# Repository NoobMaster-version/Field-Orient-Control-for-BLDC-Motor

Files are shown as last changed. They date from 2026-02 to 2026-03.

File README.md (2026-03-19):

# Field-Orient-Control-for-BLDC-Motor

STM32G431 + DRV8311H BLDC control project using STM32CubeIDE.

## Main components
- `STM32G431CBT6` (MCU)
- `DRV8311H` (3-phase gate driver)
- `AS5600` (magnetic encoder)
- `LDL1117` (voltage regulator)

This repo includes:
- `firmware/3xPWM_FOC` (FOC firmware project)
- `firmware/Open_Loop_Test_DRV8311` (open-loop bring-up test)

## Hardware

### Soldered PCB
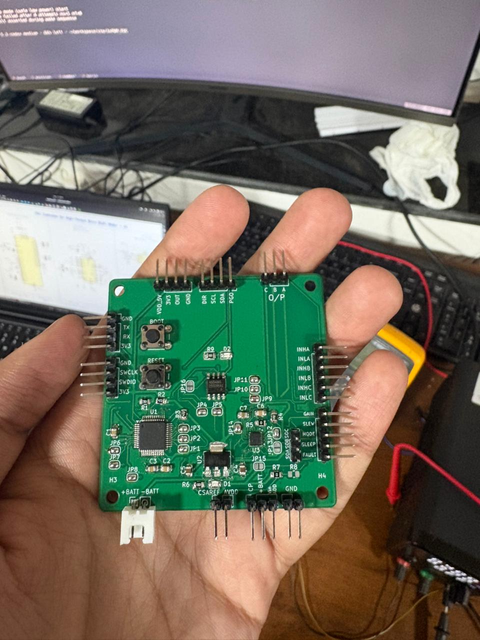
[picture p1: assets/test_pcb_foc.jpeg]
Soldered PCB


### Motor running (open-loop)
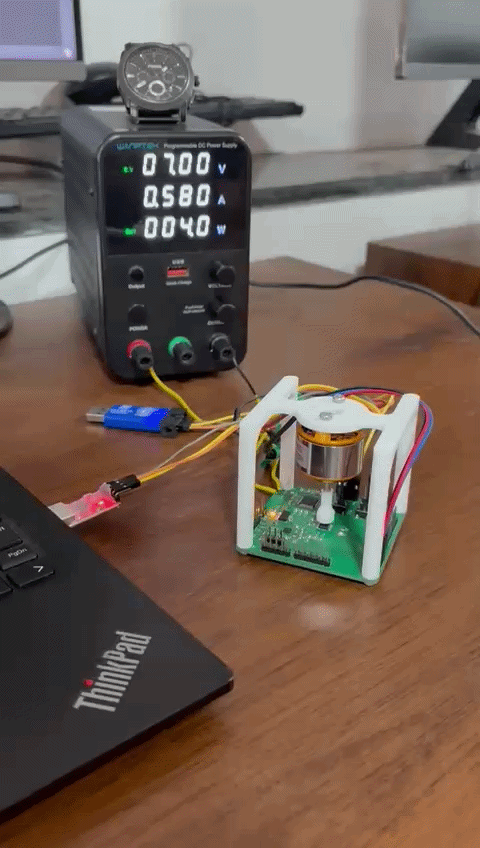
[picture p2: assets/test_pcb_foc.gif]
Open loop motor test


## PWM mode (3x PWM)

The firmware uses **3x PWM** with `TIM1` and complementary outputs to drive DRV8311:
- `INHA` from `PA8  (TIM1_CH1)`
- `INHB` from `PA9  (TIM1_CH2)`
- `INHC` from `PA10 (TIM1_CH3)`

- `INLA` from `PB13 (TIM1_CH1N)`
- `INLB` from `PB14 (TIM1_CH2N)`
- `INLC` from `PB15 (TIM1_CH3N)`

## Pin connections (STM32 -> DRV8311 / interface)

### Gate driver control
- `PA8  (TIM1_CH1)`  -> `INHA`
- `PA9  (TIM1_CH2)`  -> `INHB`
- `PA10 (TIM1_CH3)`  -> `INHC`

- `PB13 (TIM1_CH1N)` -> `INLA`
- `PB14 (TIM1_CH2N)` -> `INLB`
- `PB15 (TIM1_CH3N)` -> `INLC`

- `PC13 (GPIO)`      -> `nSLEEP`
- `PC14 (GPIO input)`-> `nFAULT` (pull-up)

### Current sensing
- `PA0 (ADC1_IN1)` -> `SOA`
- `PA1 (ADC2_IN2)` -> `SOB`
- `PA2 (ADC1_IN3)` -> `SOC`

### Encoder and debug
- `PA15 (I2C1_SCL)` -> AS5600 `SCL`
- `PB7  (I2C1_SDA)` -> AS5600 `SDA`
- `PB10 (USART3_TX)` -> UART TX (debug)
- `PB11 (USART3_RX)` -> UART RX (debug)

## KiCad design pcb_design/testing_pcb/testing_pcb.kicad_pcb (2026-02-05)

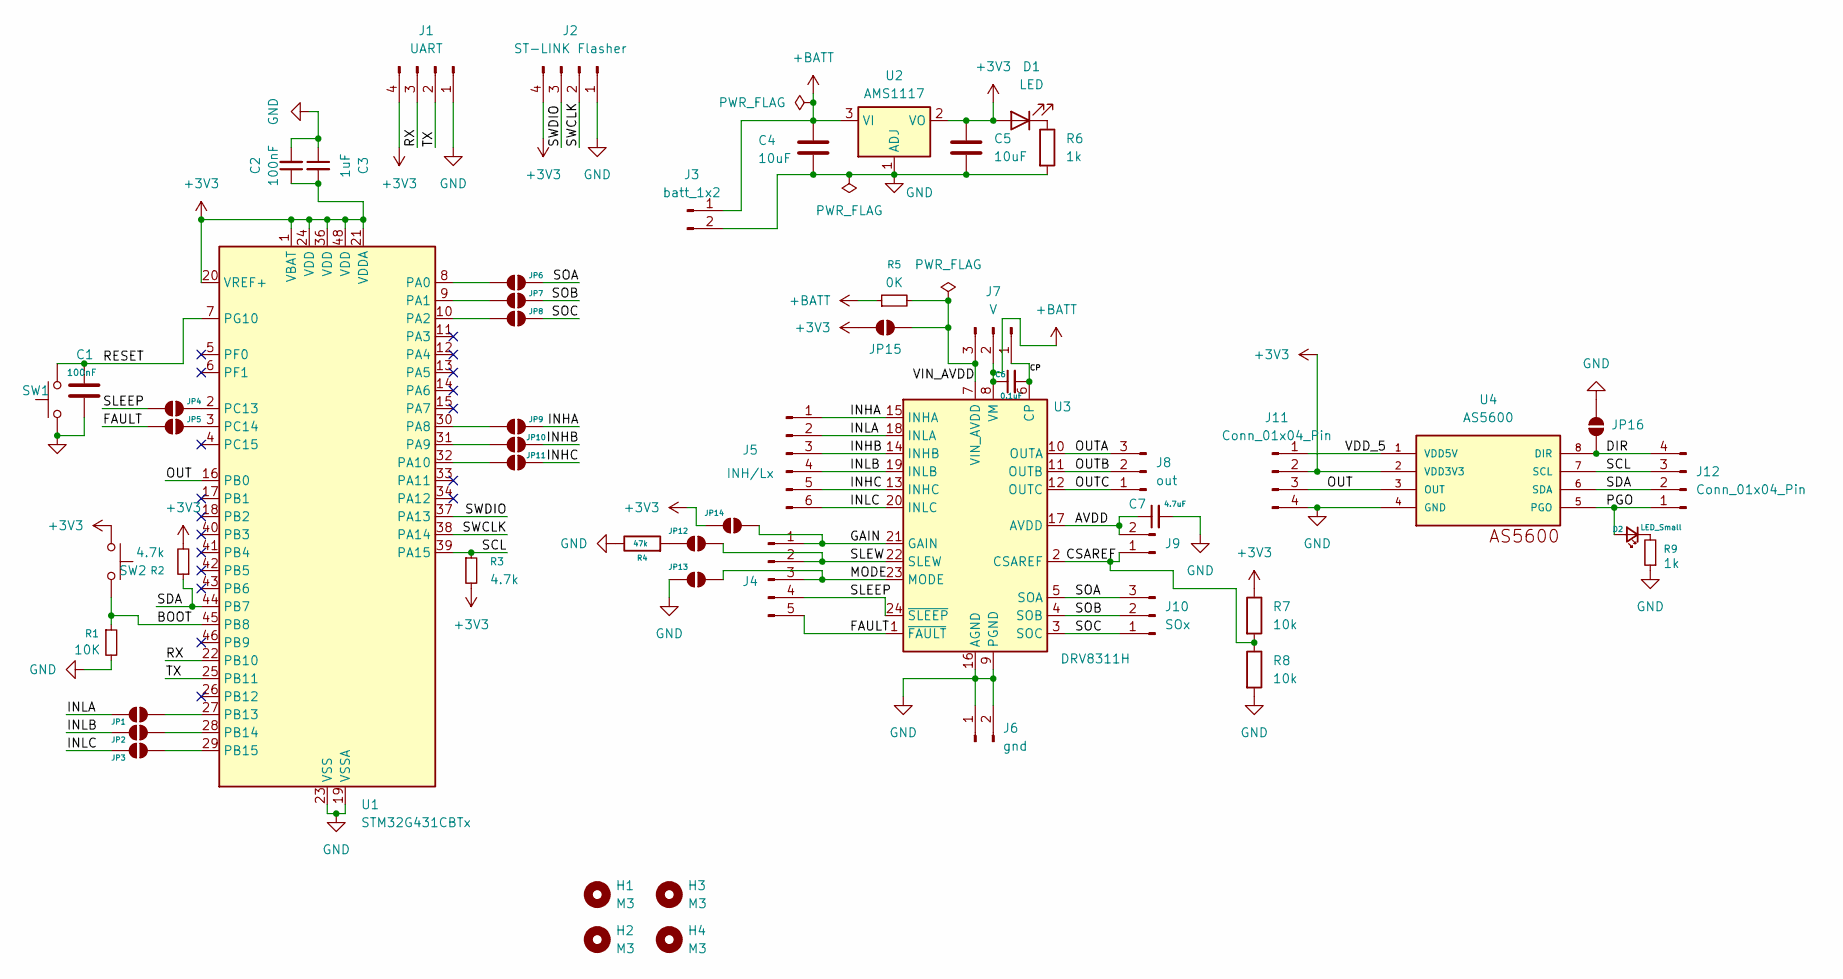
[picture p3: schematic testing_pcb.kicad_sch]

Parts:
C1: 100nF; C_0805_2012Metric_Pad1.18x1.45mm_HandSolder
C2: 100nF; C_0805_2012Metric
C3: 1uF; C_0805_2012Metric
C4, C5: 10uF; C_0805_2012Metric
C6: 0.1uF; C_0805_2012Metric
C7: 4.7uF; C_0805_2012Metric
D1: LED; LED_0805_2012Metric
D2: LED_Small; LED_0805_2012Metric
H1, H2, H3, H4: M3; MountingHole_3mm
J1: UART; PinSocket_1x04_P2.54mm_Vertical
J2: ST-LINK Flasher; PinSocket_1x04_P2.54mm_Vertical
J3: batt_1x2; PinSocket_1x02_P2.54mm_Vertical
J4: PinSocket_1x05_P2.54mm_Vertical
J5: INH/Lx; PinSocket_1x06_P2.54mm_Vertical
J6: gnd; PinSocket_1x02_P2.54mm_Vertical
J7: V; PinSocket_1x03_P2.54mm_Vertical
J8: out; PinSocket_1x03_P2.54mm_Vertical
J9: PinSocket_1x02_P2.54mm_Vertical
J10: SOx; PinSocket_1x03_P2.54mm_Vertical
J11, J12: Conn_01x04_Pin; PinSocket_1x04_P2.54mm_Vertical
JP1, JP2, JP3, JP4, JP5, JP6, JP7, JP8, JP9, JP10, JP11, JP12, JP13, JP14, JP15, JP16: SolderJumper_2_Open; SolderJumper-2_P1.3mm_Open_RoundedPad1.0x1.5mm
R1: 10K; R_0805_2012Metric
R2, R3: 4.7k; R_0805_2012Metric
R4: 47k; R_0805_2012Metric
R5: 0K; R_0805_2012Metric
R6: 1k; R_0805_2012Metric
R7, R8: 10k; R_0805_2012Metric
R9: 1k; LED_0805_2012Metric
SW1, SW2: SW_Push; SW_PUSH_6mm_H5mm
U1: STM32G431CBTx; LQFP-48_7x7mm_P0.5mm
U2: AMS1117; SOT-223-3_TabPin2
U3: DRV8311H; Texas_RRW0024A_WQFN-24-1EP_3x3mm_P0.4mm_EP1.9x1.9mm
U4: AS5600; SOIC8

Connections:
+3V3: C2.1, C3.2, C5.1, D1.2 (A), J1.4, J2.4, J11.2, JP14.1 (A), JP15.1 (A), R2.2, R3.2, R7.1, SW2.1, U1.1 (VBAT), U1.20 (VREF+), U1.21 (VDDA), U1.24 (VDD), U1.36 (VDD), U1.48 (VDD), U2.2 (VO), U4.2 (VDD3V3); also elsewhere on the board
+BATT: C4.1, C6.1, J3.1, J7.2, R5.1, U2.3 (VI), U3.8 (VM)
/AVDD: C7.1, J9.2, U3.17 (AVDD)
/BOOT: R1.1, SW2.2, U1.45 (PB8); also elsewhere on the board
/CP: C6.2, J7.1, U3.6 (CP)
/CSAREF: J9.1, R7.2, R8.1, U3.2 (CSAREF)
/DIR: J12.4, JP16.1 (A), U4.8 (DIR)
/FAULT: J4.5, JP5.1 (A), U3.1 (~FAULT)
/GAIN: J4.1, JP14.2 (B), U3.21 (GAIN)
/INHA: J5.1, JP9.2 (B), U3.15 (INHA)
/INHB: J5.3, JP10.2 (B), U3.14 (INHB)
/INHC: J5.5, JP11.2 (B), U3.13 (INHC)
/INLA: J5.2, JP1.2 (B), U3.18 (INLA)
/INLB: J5.4, JP2.2 (B), U3.19 (INLB)
/INLC: J5.6, JP3.2 (B), U3.20 (INLC)
/MODE: J4.3, JP13.2 (B), U3.23 (MODE)
/OUT: J11.3, U1.16 (PB0), U4.3 (OUT)
/OUTA: J8.3, U3.10 (OUTA)
/OUTB: J8.2, U3.11 (OUTB)
/OUTC: J8.1, U3.12 (OUTC)
/PGO: D2.2 (A), J12.1, U4.5 (PGO)
/RESET: C1.1, SW1.2, U1.7 (PG10); also elsewhere on the board
/RX: J1.3, U1.22 (PB10); also elsewhere on the board
/SCL: J12.3, R3.1, U1.39 (PA15), U4.7 (SCL)
/SDA: J12.2, R2.1, U1.44 (PB7), U4.6 (SDA)
/SLEEP: J4.4, JP4.1 (A), U3.24 (~SLEEP)
/SLEW: J4.2, JP12.2 (B), U3.22 (SLEW)
/SOA: J10.3, JP6.2 (B), U3.5 (SOA)
/SOB: J10.2, JP7.2 (B), U3.4 (SOB)
/SOC: J10.1, JP8.2 (B), U3.3 (SOC)
/SWCLK: J2.2, U1.38 (PA14)
/SWDIO: J2.3, U1.37 (PA13)
/TX: J1.2, U1.25 (PB11); also elsewhere on the board
/VDD_5: J11.1, U4.1 (VDD5V)
/VIN_AVDD: J7.3, JP15.2 (B), R5.2, U3.7 (VIN_AVDD)
GND: C1.2, C2.2, C3.1, C4.2, C5.2, C7.2, J1.1, J2.1, J3.2, J6.1, J6.2, J11.4, JP13.1 (A), JP16.2 (B), R1.2, R4.1, R6.2, R8.2, R9.1, SW1.1, U1.19 (VSSA), U1.23 (VSS), U1.35 (VSS), U1.47 (VSS), U2.1 (ADJ), U3.9 (PGND), U3.16 (AGND), U3.25 (PGND), U4.4 (GND); also elsewhere on the board
unnamed: D1.1 (K), R6.1
unnamed: D2.1 (K), R9.2
unnamed: JP1.1 (A), U1.27 (PB13)
unnamed: JP2.1 (A), U1.28 (PB14)
unnamed: JP3.1 (A), U1.29 (PB15)
unnamed: JP4.2 (B), U1.2 (PC13)
unnamed: JP5.2 (B), U1.3 (PC14)
unnamed: JP6.1 (A), U1.8 (PA0)
unnamed: JP7.1 (A), U1.9 (PA1)
unnamed: JP8.1 (A), U1.10 (PA2)
unnamed: JP9.1 (A), U1.30 (PA8)
unnamed: JP10.1 (A), U1.31 (PA9)
unnamed: JP11.1 (A), U1.32 (PA10)
unnamed: JP12.1 (A), R4.2

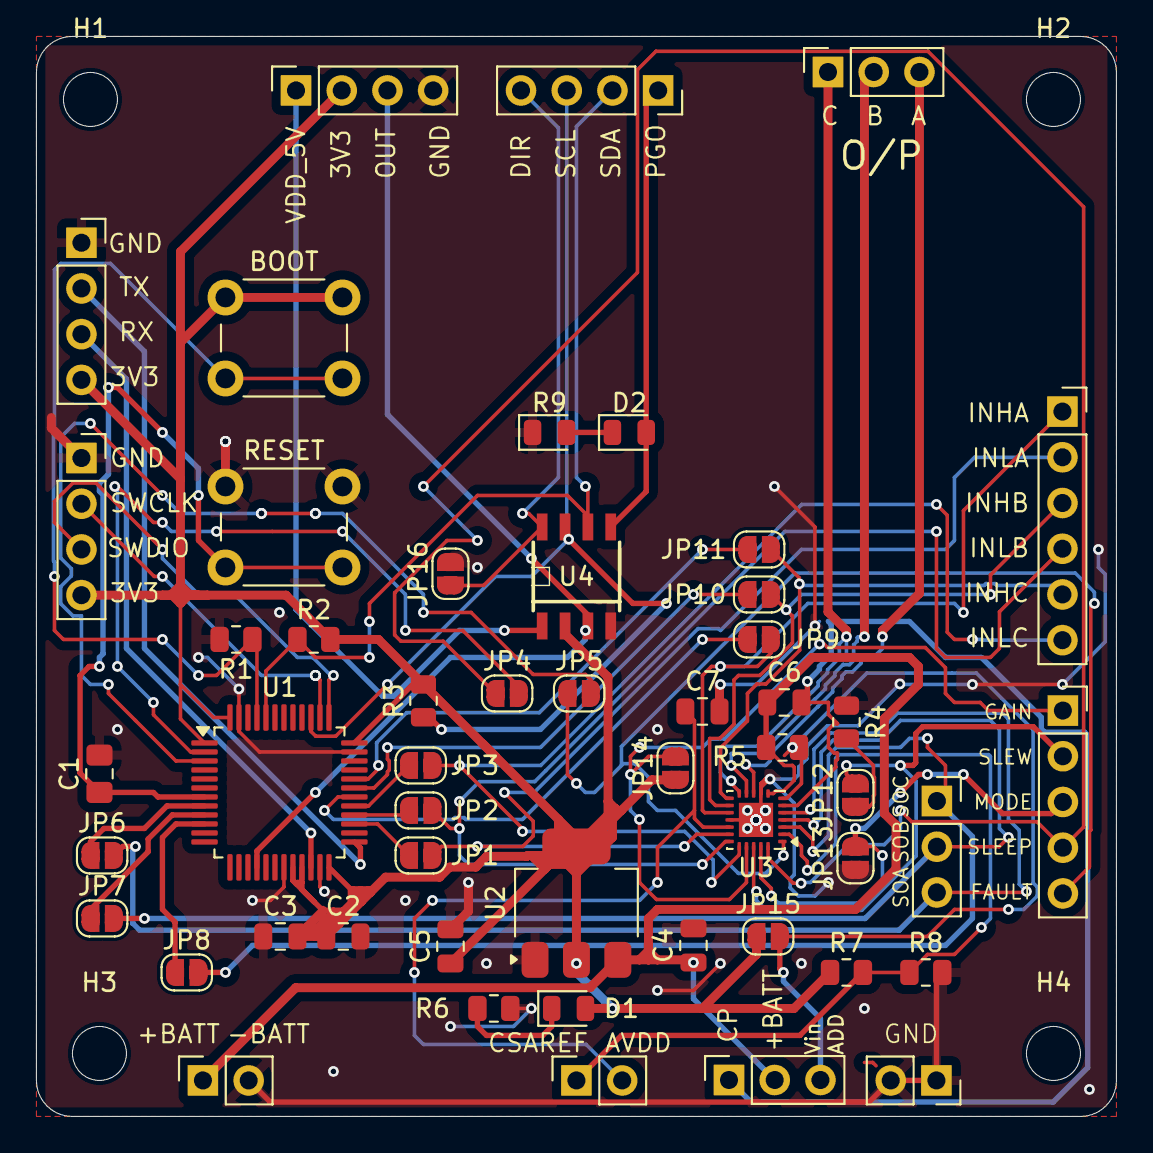
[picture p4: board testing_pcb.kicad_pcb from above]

Board: 2 copper layers, 60.0 x 60.0 mm, 56 parts (0 on the bottom side), 50 nets.

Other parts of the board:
BOOT: SW_Push; SW_PUSH_6mm_H5mm
GND: UART; PinSocket_1x04_P2.54mm_Vertical
RESET: SW_Push; SW_PUSH_6mm_H5mm

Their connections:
+3V3: BOOT.1, GND.4; also elsewhere on the board
/BOOT: BOOT.2; also elsewhere on the board
/RESET: RESET.2; also elsewhere on the board
/RX: GND.3; also elsewhere on the board
/TX: GND.2; also elsewhere on the board
GND: GND.1, RESET.1; also elsewhere on the board

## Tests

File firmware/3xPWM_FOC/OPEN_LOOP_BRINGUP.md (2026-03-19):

# STM32G431 + DRV8311H Bring-Up

## CubeMX setup

- `RCC`: use `HSI` with PLL to `170 MHz`.
- `TIM1`: center-aligned PWM, `Prescaler = 0`, `Period = 1699`, CH1/CH2/CH3 enabled on `PA8/PA9/PA10`, `TRGO = Update`.
- `ADC1`: regular conversion sequence with `PA0 = IN1` and `PA2 = IN3`, external trigger `TIM1 TRGO`, DMA enabled, 12-bit, sample time `47.5 cycles`.
- `ADC2`: single conversion on `PA1 = IN2`, software trigger, 12-bit, sample time `47.5 cycles`.
- `I2C1`: `PA15 = SCL`, `PB7 = SDA`, timing value `0x40B285C2`.
- `USART3`: `PB10 = TX`, `PB11 = RX`, `115200 8N1`.
- `GPIO output`: `PC13 = nSLEEP`, `PB13/PB14/PB15 = INLA/INLB/INLC`.
- `GPIO input`: `PC14 = nFAULT` with pull-up.

## Bring-up sequence

1. Keep `nSLEEP` low during reset.
2. Start TIM1 PWM with all three duties at `50%`.
3. Drive `PB13/PB14/PB15` high if your DRV8311H mode really is `3x PWM`.
4. Calibrate ADC offsets with zero commanded voltage.
5. Raise `nSLEEP`, check `nFAULT`, and stop immediately if a fault is active.
6. Apply a fixed electrical angle for about `1.2 s` to align the rotor.
7. Ramp electrical speed slowly to about `1.2 electrical Hz`.
8. Print phase currents and AS5600 angle over UART at `10 Hz`.

## Required hardware checks

- Do not leave `MODE` floating on the final board. Strap it to the mode you actually want after checking the DRV8311H truth table.
- Confirm your shunt resistor value and update `SHUNT_RESISTOR_OHMS` in [main.c](/home/raze/workspace/stm/3xPWM_FOC/Core/Src/main.c).
- Confirm the DRV current-sense output common-mode behavior matches the code assumption of a midscale zero-current offset.
- If the motor twitches but does not rotate, swap any two motor phases or invert the open-loop angle direction.
- For a `4300 KV` 1S motor, keep startup modulation low. Your current code clamps normal run modulation to `4.5%`.

## What to implement next

1. Encoder validation: verify AS5600 angle is monotonic through one full mechanical revolution.
2. Electrical angle calibration: lock rotor at a known phase vector and measure encoder offset.
3. Closed-loop current sensing: move from slow debug reads to timer-synchronous sampling for all phases.
4. FOC transforms: Clarke, Park, inverse Park, and SVPWM or sinusoidal PWM.
5. Current PI loops: `Id` and `Iq`.
6. Velocity loop: use AS5600 derived speed as the outer loop.

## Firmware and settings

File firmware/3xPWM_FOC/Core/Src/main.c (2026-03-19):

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
/* Includes ------------------------------------------------------------------*/
#include "main.h"

/* USER CODE BEGIN Includes */
#include <math.h>
#include <stdio.h>
#include <string.h>
/* USER CODE END Includes */

/* USER CODE BEGIN PD */
#define PWM_PERIOD_TICKS         1699U
#define PWM_CENTER_TICKS         ((PWM_PERIOD_TICKS + 1U) / 2U)
#define PWM_FREQ_HZ              50000.0f

#define ADC_FULL_SCALE           4095.0f
#define ADC_VREF_V               3.3f
#define SHUNT_RESISTOR_OHMS      0.010f
#define CSA_GAIN_V_V             20.0f

#define OPEN_LOOP_ALIGN_MOD      0.025f
#define OPEN_LOOP_RUN_MOD        0.030f
#define OPEN_LOOP_ALIGN_MS       1200U
#define OPEN_LOOP_TARGET_EHZ     0.8f
#define OPEN_LOOP_RAMP_EHZ_S     0.25f

#define UART_PRINT_PERIOD_MS     100U
#define CURRENT_OFFSET_SAMPLES   256U
#define DRV_POWER_SETTLE_MS      50U
#define DRV_WAKE_TIMEOUT_MS      100U
#define DRV_FAULT_RELEASE_MS     2U

#define PI_F                     3.14159265359f
#define TWO_PI_F                 (2.0f * PI_F)

#define AS5600_I2C_ADDR          (0x36U << 1)
#define AS5600_REG_ANGLE_MSB     0x0EU

#define DRV_NSLEEP_GPIO_Port     GPIOC
#define DRV_NSLEEP_Pin           GPIO_PIN_13
#define DRV_NFAULT_GPIO_Port     GPIOC
#define DRV_NFAULT_Pin           GPIO_PIN_14

#define DRV_INL_GPIO_Port        GPIOB
#define DRV_INLA_Pin             GPIO_PIN_13
#define DRV_INLB_Pin             GPIO_PIN_14
#define DRV_INLC_Pin             GPIO_PIN_15
/* USER CODE END PD */

ADC_HandleTypeDef hadc1;
ADC_HandleTypeDef hadc2;
DMA_HandleTypeDef hdma_adc1;

I2C_HandleTypeDef hi2c1;

TIM_HandleTypeDef htim1;

UART_HandleTypeDef huart3;

/* USER CODE BEGIN PV */
static volatile uint32_t adc1_dma_buf[2];

static float ia_offset_counts = 2048.0f;
static float ib_offset_counts = 2048.0f;
static float ic_offset_counts = 2048.0f;

static float electrical_angle = 0.0f;
static float electrical_hz = 0.0f;
/* USER CODE END PV */

void SystemClock_Config(void);
static void MX_GPIO_Init(void);
static void MX_DMA_Init(void);
static void MX_ADC1_Init(void);
static void MX_ADC2_Init(void);
static void MX_I2C1_Init(void);
static void MX_TIM1_Init(void);
static void MX_USART3_UART_Init(void);
/* USER CODE BEGIN PFP */
static void Error_Stop(const char *msg);
static void uart_write(const char *msg);
static void drv_disable(void);
static void drv_enable(void);
static uint8_t drv_has_fault(void);
static uint8_t drv_fault_released_for_ms(uint32_t hold_ms);
static void phase_inputs_low_side_enable(void);
static void phase_inputs_disable(void);
static uint8_t drv_wake_and_check(uint32_t retries, char *msg, uint32_t msg_len);
static void set_three_phase_duty(float duty_a, float duty_b, float duty_c);
static void set_open_loop_voltage(float angle_rad, float modulation);
static uint16_t as5600_read_raw_angle(void);
static float as5600_read_deg(void);
static uint32_t adc2_read_raw_blocking(void);
static void calibrate_current_offsets(void);
static float current_from_adc_counts(float raw_counts, float offset_counts);
static float wrap_angle_0_2pi(float angle);
/* USER CODE END PFP */

/* USER CODE BEGIN 0 */
static void uart_write(const char *msg)
{
  HAL_UART_Transmit(&huart3, (uint8_t *)msg, (uint16_t)strlen(msg), 100U);
}

int __io_putchar(int ch)
{
  HAL_UART_Transmit(&huart3, (uint8_t *)&ch, 1U, 10U);
  return ch;
}

static void Error_Stop(const char *msg)
{
  set_three_phase_duty(0.5f, 0.5f, 0.5f);
  drv_disable();
  if (msg != NULL)
  {
    uart_write(msg);
  }
  while (1)
  {
  }
}

static void drv_disable(void)
{
  HAL_GPIO_WritePin(DRV_NSLEEP_GPIO_Port, DRV_NSLEEP_Pin, GPIO_PIN_RESET);
}

static void drv_enable(void)
{
  HAL_GPIO_WritePin(DRV_NSLEEP_GPIO_Port, DRV_NSLEEP_Pin, GPIO_PIN_SET);
}

static uint8_t drv_has_fault(void)
{
  return (HAL_GPIO_ReadPin(DRV_NFAULT_GPIO_Port, DRV_NFAULT_Pin) == GPIO_PIN_RESET) ? 1U : 0U;
}

static uint8_t drv_fault_released_for_ms(uint32_t hold_ms)
{
  uint32_t stable_since;

  if (drv_has_fault() != 0U)
  {
    return 0U;
  }

  stable_since = HAL_GetTick();
  while ((HAL_GetTick() - stable_since) < hold_ms)
  {
    if (drv_has_fault() != 0U)
    {
      return 0U;
    }
  }

  return 1U;
}

static void phase_inputs_low_side_enable(void)
{
  HAL_GPIO_WritePin(DRV_INL_GPIO_Port, DRV_INLA_Pin | DRV_INLB_Pin | DRV_INLC_Pin, GPIO_PIN_SET);
}

static void phase_inputs_disable(void)
{
  HAL_GPIO_WritePin(DRV_INL_GPIO_Port, DRV_INLA_Pin | DRV_INLB_Pin | DRV_INLC_Pin, GPIO_PIN_RESET);
}

static uint8_t drv_wake_and_check(uint32_t retries, char *msg, uint32_t msg_len)
{
  uint32_t attempt;
  uint32_t start_tick;

  drv_disable();
  HAL_Delay(2U);

  for (attempt = 0U; attempt < retries; attempt++)
  {
    if (attempt != 0U)
    {
      drv_disable();
      HAL_Delay(2U);
    }

    drv_enable();
    start_tick = HAL_GetTick();

    while ((HAL_GetTick() - start_tick) < DRV_WAKE_TIMEOUT_MS)
    {
      if (drv_fault_released_for_ms(DRV_FAULT_RELEASE_MS) != 0U)
      {
        if (msg != NULL)
        {
          snprintf(msg, msg_len,
                   "DRV wake OK at attempt=%lu ns=%u nf=%u\r\n",
                   (unsigned long)(attempt + 1U),
                   (unsigned int)HAL_GPIO_ReadPin(DRV_NSLEEP_GPIO_Port, DRV_NSLEEP_Pin),
                   (unsigned int)HAL_GPIO_ReadPin(DRV_NFAULT_GPIO_Port, DRV_NFAULT_Pin));
        }
        return 1U;
      }

      HAL_Delay(1U);
    }
  }

  if (msg != NULL)
  {
    snprintf(msg, msg_len,
             "DRV wake failed after %lu attempts ns=%u nf=%u (check nFAULT pull-up to AVDD, VM, MODE strap)\r\n",
             (unsigned long)retries,
             (unsigned int)HAL_GPIO_ReadPin(DRV_NSLEEP_GPIO_Port, DRV_NSLEEP_Pin),
             (unsigned int)HAL_GPIO_ReadPin(DRV_NFAULT_GPIO_Port, DRV_NFAULT_Pin));
  }
  return 0U;
}

static float clamp01(float x)
{
  if (x < 0.0f)
  {
    return 0.0f;
  }
  if (x > 1.0f)
  {
    return 1.0f;
  }
  return x;
}

static void set_three_phase_duty(float duty_a, float duty_b, float duty_c)
{
  uint32_t ccr_a = (uint32_t)(clamp01(duty_a) * (float)(PWM_PERIOD_TICKS + 1U));
  uint32_t ccr_b = (uint32_t)(clamp01(duty_b) * (float)(PWM_PERIOD_TICKS + 1U));
  uint32_t ccr_c = (uint32_t)(clamp01(duty_c) * (float)(PWM_PERIOD_TICKS + 1U));

  if (ccr_a > PWM_PERIOD_TICKS)
  {
    ccr_a = PWM_PERIOD_TICKS;
  }
  if (ccr_b > PWM_PERIOD_TICKS)
  {
    ccr_b = PWM_PERIOD_TICKS;
  }
  if (ccr_c > PWM_PERIOD_TICKS)
  {
    ccr_c = PWM_PERIOD_TICKS;
  }

  __HAL_TIM_SET_COMPARE(&htim1, TIM_CHANNEL_1, ccr_a);
  __HAL_TIM_SET_COMPARE(&htim1, TIM_CHANNEL_2, ccr_b);
  __HAL_TIM_SET_COMPARE(&htim1, TIM_CHANNEL_3, ccr_c);
}

static float wrap_angle_0_2pi(float angle)
{
  while (angle >= TWO_PI_F)
  {
    angle -= TWO_PI_F;
  }
  while (angle < 0.0f)
  {
    angle += TWO_PI_F;
  }
  return angle;
}

static void set_open_loop_voltage(float angle_rad, float modulation)
{
  float va;
  float vb;
  float vc;

  if (modulation < 0.0f)
  {
    modulation = 0.0f;
  }
  if (modulation > 0.12f)
  {
    modulation = 0.12f;
  }

  angle_rad = wrap_angle_0_2pi(angle_rad);

  va = sinf(angle_rad);
  vb = sinf(angle_rad - (TWO_PI_F / 3.0f));
  vc = sinf(angle_rad + (TWO_PI_F / 3.0f));

  set_three_phase_duty(0.5f + 0.5f * modulation * va,
                       0.5f + 0.5f * modulation * vb,
                       0.5f + 0.5f * modulation * vc);
}

static uint16_t as5600_read_raw_angle(void)
{
  uint8_t reg = AS5600_REG_ANGLE_MSB;
  uint8_t data[2] = {0U, 0U};

  if (HAL_I2C_Master_Transmit(&hi2c1, AS5600_I2C_ADDR, &reg, 1U, 20U) != HAL_OK)
  {
    return 0xFFFFU;
  }

  if (HAL_I2C_Master_Receive(&hi2c1, AS5600_I2C_ADDR, data, 2U, 20U) != HAL_OK)
  {
    return 0xFFFFU;
  }

  return (uint16_t)(((uint16_t)(data[0] & 0x0FU) << 8) | data[1]);
}

static float as5600_read_deg(void)
{
  uint16_t raw = as5600_read_raw_angle();
  if (raw == 0xFFFFU)
  {
    return -1.0f;
  }
  return ((float)raw * 360.0f) / 4096.0f;
}

static uint32_t adc2_read_raw_blocking(void)
{
  if (HAL_ADC_Start(&hadc2) != HAL_OK)
  {
    return 0U;
  }

  if (HAL_ADC_PollForConversion(&hadc2, 5U) != HAL_OK)
  {
    HAL_ADC_Stop(&hadc2);
    return 0U;
  }

  uint32_t value = HAL_ADC_GetValue(&hadc2);
  HAL_ADC_Stop(&hadc2);
  return value;
}

static void calibrate_current_offsets(void)
{
  uint32_t i;
  uint64_t sum_a = 0U;
  uint64_t sum_b = 0U;
  uint64_t sum_c = 0U;

  set_three_phase_duty(0.5f, 0.5f, 0.5f);
  HAL_Delay(20U);

  for (i = 0U; i < CURRENT_OFFSET_SAMPLES; i++)
  {
    HAL_Delay(1U);
    sum_a += adc1_dma_buf[0];
    sum_b += adc2_read_raw_blocking();
    sum_c += adc1_dma_buf[1];
  }

  ia_offset_counts = (float)sum_a / (float)CURRENT_OFFSET_SAMPLES;
  ib_offset_counts = (float)sum_b / (float)CURRENT_OFFSET_SAMPLES;
  ic_offset_counts = (float)sum_c / (float)CURRENT_OFFSET_SAMPLES;
}

static float current_from_adc_counts(float raw_counts, float offset_counts)
{
  float delta_v = ((raw_counts - offset_counts) / ADC_FULL_SCALE) * ADC_VREF_V;
  return delta_v / (CSA_GAIN_V_V * SHUNT_RESISTOR_OHMS);
}
/* USER CODE END 0 */

/**
  * @brief  The application entry point.
  * @retval int
  */
int main(void)
{
  uint32_t last_tick;
  uint32_t last_print_tick;
  uint32_t now;
  uint32_t dt_ms;
  float dt_s;
  uint32_t raw_b;
  float ia;
  float ib;
  float ic;
  float enc_deg;
  int32_t ia_mA;
  int32_t ib_mA;
  int32_t ic_mA;
  int32_t sum_mA;
  int32_t enc_t10;
  int32_t ehz_x1000;
  char tx[192];

  HAL_Init();
  SystemClock_Config();

  MX_GPIO_Init();
  MX_DMA_Init();
  MX_ADC1_Init();
  MX_ADC2_Init();
  MX_I2C1_Init();
  MX_TIM1_Init();
  MX_USART3_UART_Init();

  drv_disable();
  phase_inputs_disable();
  set_three_phase_duty(0.5f, 0.5f, 0.5f);

  uart_write("\r\nOpen-loop mode (safe low power) start\r\n");

  if (HAL_ADCEx_Calibration_Start(&hadc1, ADC_SINGLE_ENDED) != HAL_OK)
  {
    Error_Handler();
  }
  if (HAL_ADCEx_Calibration_Start(&hadc2, ADC_SINGLE_ENDED) != HAL_OK)
  {
    Error_Handler();
  }

  if (HAL_TIM_PWM_Start(&htim1, TIM_CHANNEL_1) != HAL_OK)
  {
    Error_Handler();
  }
  if (HAL_TIM_PWM_Start(&htim1, TIM_CHANNEL_2) != HAL_OK)
  {
    Error_Handler();
  }
  if (HAL_TIM_PWM_Start(&htim1, TIM_CHANNEL_3) != HAL_OK)
  {
    Error_Handler();
  }

  set_three_phase_duty(0.5f, 0.5f, 0.5f);
  phase_inputs_low_side_enable();
  HAL_Delay(1U);
  HAL_Delay(DRV_POWER_SETTLE_MS);

  if (drv_wake_and_check(2U, tx, sizeof(tx)) == 0U)
  {
    uart_write(tx);
    uart_write("DRV fault asserted during wake sequence; holding diagnostic state\r\n");
    while (1)
    {
      snprintf(tx, sizeof(tx),
               "WAKE_FAIL ns=%u nf=%u (check external nFAULT pull-up, VM, MODE)\r\n",
               (unsigned int)HAL_GPIO_ReadPin(DRV_NSLEEP_GPIO_Port, DRV_NSLEEP_Pin),
               (unsigned int)HAL_GPIO_ReadPin(DRV_NFAULT_GPIO_Port, DRV_NFAULT_Pin));
      uart_write(tx);
      HAL_Delay(250U);
    }
  }
  uart_write(tx);

  if (drv_has_fault() != 0U)
  {
    snprintf(tx, sizeof(tx),
             "Fault after PWM/INL enable: ns=%u nf=%u\r\n",
             (unsigned int)HAL_GPIO_ReadPin(DRV_NSLEEP_GPIO_Port, DRV_NSLEEP_Pin),
             (unsigned int)HAL_GPIO_ReadPin(DRV_NFAULT_GPIO_Port, DRV_NFAULT_Pin));
    uart_write(tx);
    Error_Stop("DRV fault asserted after PWM start\r\n");
  }

  if (HAL_ADC_Start_DMA(&hadc1, (uint32_t *)adc1_dma_buf, 2U) != HAL_OK)
  {
    Error_Handler();
  }

  calibrate_current_offsets();
  set_open_loop_voltage(0.0f, OPEN_LOOP_ALIGN_MOD);
  HAL_Delay(OPEN_LOOP_ALIGN_MS);

  electrical_angle = 0.0f;
  electrical_hz = 0.0f;
  last_tick = HAL_GetTick();
  last_print_tick = last_tick;

  while (1)
  {
    now = HAL_GetTick();
    dt_ms = now - last_tick;
    if (dt_ms == 0U)
    {
      continue;
    }
    last_tick = now;
    dt_s = (float)dt_ms * 0.001f;

    if (drv_has_fault() != 0U)
    {
      Error_Stop("DRV fault during run\r\n");
    }

    if (electrical_hz < OPEN_LOOP_TARGET_EHZ)
    {
      electrical_hz += OPEN_LOOP_RAMP_EHZ_S * dt_s;
      if (electrical_hz > OPEN_LOOP_TARGET_EHZ)
      {
        electrical_hz = OPEN_LOOP_TARGET_EHZ;
      }
    }

    electrical_angle += TWO_PI_F * electrical_hz * dt_s;
    electrical_angle = wrap_angle_0_2pi(electrical_angle);
    set_open_loop_voltage(electrical_angle, OPEN_LOOP_RUN_MOD);

    raw_b = adc2_read_raw_blocking();
    ia = current_from_adc_counts((float)adc1_dma_buf[0], ia_offset_counts);
    ib = current_from_adc_counts((float)raw_b, ib_offset_counts);
    ic = current_from_adc_counts((float)adc1_dma_buf[1], ic_offset_counts);
    enc_deg = as5600_read_deg();
    ia_mA = (int32_t)(ia * 1000.0f);
    ib_mA = (int32_t)(ib * 1000.0f);
    ic_mA = (int32_t)(ic * 1000.0f);
    sum_mA = ia_mA + ib_mA + ic_mA;
    enc_t10 = (enc_deg < 0.0f) ? -1 : (int32_t)(enc_deg * 10.0f);
    ehz_x1000 = (int32_t)(electrical_hz * 1000.0f);

    if ((now - last_print_tick) >= UART_PRINT_PERIOD_MS)
    {
      last_print_tick = now;
      snprintf(tx, sizeof(tx),
               "ehz_x1000=%ld ns=%u nf=%u IA_mA=%ld IB_mA=%ld IC_mA=%ld SUM_mA=%ld ENC_t10=%ld SOB=%lu\r\n",
               (long)ehz_x1000,
               (unsigned int)HAL_GPIO_ReadPin(DRV_NSLEEP_GPIO_Port, DRV_NSLEEP_Pin),
               (unsigned int)HAL_GPIO_ReadPin(DRV_NFAULT_GPIO_Port, DRV_NFAULT_Pin),
               (long)ia_mA,
               (long)ib_mA,
               (long)ic_mA,
               (long)sum_mA,
               (long)enc_t10,
               (unsigned long)raw_b);
      uart_write(tx);
    }
  }
}

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


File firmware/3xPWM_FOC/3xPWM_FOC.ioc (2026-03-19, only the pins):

Mcu.UserName=STM32G431CBTx
PA0.Signal=ADC1_IN1
PA1.Signal=ADC2_IN2
PA10.Signal=S_TIM1_CH3
PA15.Signal=I2C1_SCL
PA2.Signal=ADC1_IN3
PA8.Signal=S_TIM1_CH1
PA9.Signal=S_TIM1_CH2
PB10.Signal=USART3_TX
PB11.Signal=USART3_RX
PB13.Signal=GPIO_Output
PB14.Signal=GPIO_Output
PB15.Signal=GPIO_Output
PB7.Signal=I2C1_SDA
PC13.Signal=GPIO_Output
PC14-OSC32_IN.Signal=GPIO_Input

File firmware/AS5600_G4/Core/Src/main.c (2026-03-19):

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
/* Includes ------------------------------------------------------------------*/
#include "main.h"

/* USER CODE BEGIN Includes */
extern I2C_HandleTypeDef hi2c1;
extern UART_HandleTypeDef huart1;
extern ADC_HandleTypeDef hadc1;

#define AS5600_ADDR (0x36 << 1)
#define RAW_ANGLE_REG 0x0C
#define STATUS_REG    0x0B

uint8_t i2c_buf[2];
uint8_t status_buf;
char uart_buf[120];
/* USER CODE END Includes */

ADC_HandleTypeDef hadc1;

I2C_HandleTypeDef hi2c1;

UART_HandleTypeDef huart1;
UART_HandleTypeDef huart3;

void SystemClock_Config(void);
static void MX_GPIO_Init(void);
static void MX_ADC1_Init(void);
static void MX_I2C1_Init(void);
static void MX_USART1_UART_Init(void);
static void MX_USART3_UART_Init(void);
/* USER CODE BEGIN 0 */
float read_i2c_angle()
{
    uint16_t raw_angle = 0;

    HAL_I2C_Mem_Read(&hi2c1,
                     AS5600_ADDR,
                     RAW_ANGLE_REG,
                     I2C_MEMADD_SIZE_8BIT,
                     i2c_buf,
                     2,
                     HAL_MAX_DELAY);

    raw_angle = (i2c_buf[0] << 8) | i2c_buf[1];

    return (raw_angle * 360.0f) / 4096.0f;
}

float read_out_angle()
{
    HAL_ADC_Start(&hadc1);
    HAL_ADC_PollForConversion(&hadc1, HAL_MAX_DELAY);

    uint32_t adc_val = HAL_ADC_GetValue(&hadc1);

    float voltage = (adc_val * 3.3f) / 4095.0f;
    float angle = (voltage / 3.3f) * 360.0f;

    return angle;
}

uint8_t magnet_detected()
{
    HAL_I2C_Mem_Read(&hi2c1,
                     AS5600_ADDR,
                     STATUS_REG,
                     I2C_MEMADD_SIZE_8BIT,
                     &status_buf,
                     1,
                     HAL_MAX_DELAY);

    // Bit 5 = MD (Magnet detected)
    if (status_buf & (1 << 5))
        return 1;
    else
        return 0;
}
/* USER CODE END 0 */

/**
  * @brief  The application entry point.
  * @retval int
  */
int main(void)
{

  /* MCU Configuration--------------------------------------------------------*/

  /* Reset of all peripherals, Initializes the Flash interface and the Systick. */
  HAL_Init();

  /* Configure the system clock */
  SystemClock_Config();

  /* Initialize all configured peripherals */
  MX_GPIO_Init();
  MX_ADC1_Init();
  MX_I2C1_Init();
  MX_USART1_UART_Init();
  MX_USART3_UART_Init();
  /* USER CODE BEGIN 2 */
  float angle_i2c, angle_out;
  uint8_t magnet_ok;

  /* USER CODE END 2 */

  /* Infinite loop */
  /* USER CODE BEGIN WHILE */
  while (1)
  {
    /* USER CODE END WHILE */
	  float angle_i2c, angle_out;
	    uint8_t magnet_ok;
	    /* USER CODE END 2 */

	    /* Infinite loop */
	    /* USER CODE BEGIN WHILE */
	    while (1)
	    {
	      angle_i2c = read_i2c_angle();
	      angle_out = read_out_angle();
	      magnet_ok = magnet_detected();

	      sprintf(uart_buf,
	              "Magnet: %s | I2C: %.2f deg | OUT: %.2f deg\r\n",
	              magnet_ok ? "OK" : "NO",
	              angle_i2c,
	              angle_out);

	      HAL_UART_Transmit(&huart3,
	                        (uint8_t*)uart_buf,
	                        strlen(uart_buf),
	                        HAL_MAX_DELAY);

	      HAL_Delay(200);
	    }

    /* USER CODE BEGIN 3 */
  }
  /* USER CODE END 3 */
}

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


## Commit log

2026-01-28 Added circuit for DRV8311 and AS5600
    [foc_controller.kicad_pcb, foc_controller.kicad_sch]
2026-02-04 test pcb updated
    [foc_controller.kicad_pcb, foc_controller.kicad_sch, testing_pcb.kicad_pcb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]
2026-02-05 added round corners , fixed acute angle turns
    [testing_pcb.kicad_pcb]
2026-03-19 Added 3xPWM firmware with AS5600 support Updated README.md
    [foc_controller.kicad_pcb, foc_controller.kicad_sch]

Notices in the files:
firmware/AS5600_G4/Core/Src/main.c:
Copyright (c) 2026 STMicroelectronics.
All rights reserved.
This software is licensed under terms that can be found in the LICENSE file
